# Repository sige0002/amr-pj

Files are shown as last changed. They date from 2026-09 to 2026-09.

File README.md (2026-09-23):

# AMR-01：E4 レビュー反映版

**機構設計とロボット・電装の独立AIレビューを受け、天板とスイッチ取付部を修正しました。** 天板は中央対称25穴、外周6点の極低頭固定、荷物止めは標準から撤去。スイッチはナット・工具・端末空間と配線保持を追加しました。

[設計・CAD画像](cad/amr07/reviewed-design/README.ja.md) ／ [標準BOM](cad/amr07/reviewed-design/BOM.ja.md) ／ [明細Markdown](cad/amr07/reviewed-design/BOM-details.ja.md) ／ [CSV](cad/amr07/reviewed-design/BOM.csv) ／ [配線](cad/amr07/reviewed-design/WIRING.ja.md) ／ [レビュー・対応表](cad/amr07/design-review-e3/README.ja.md)

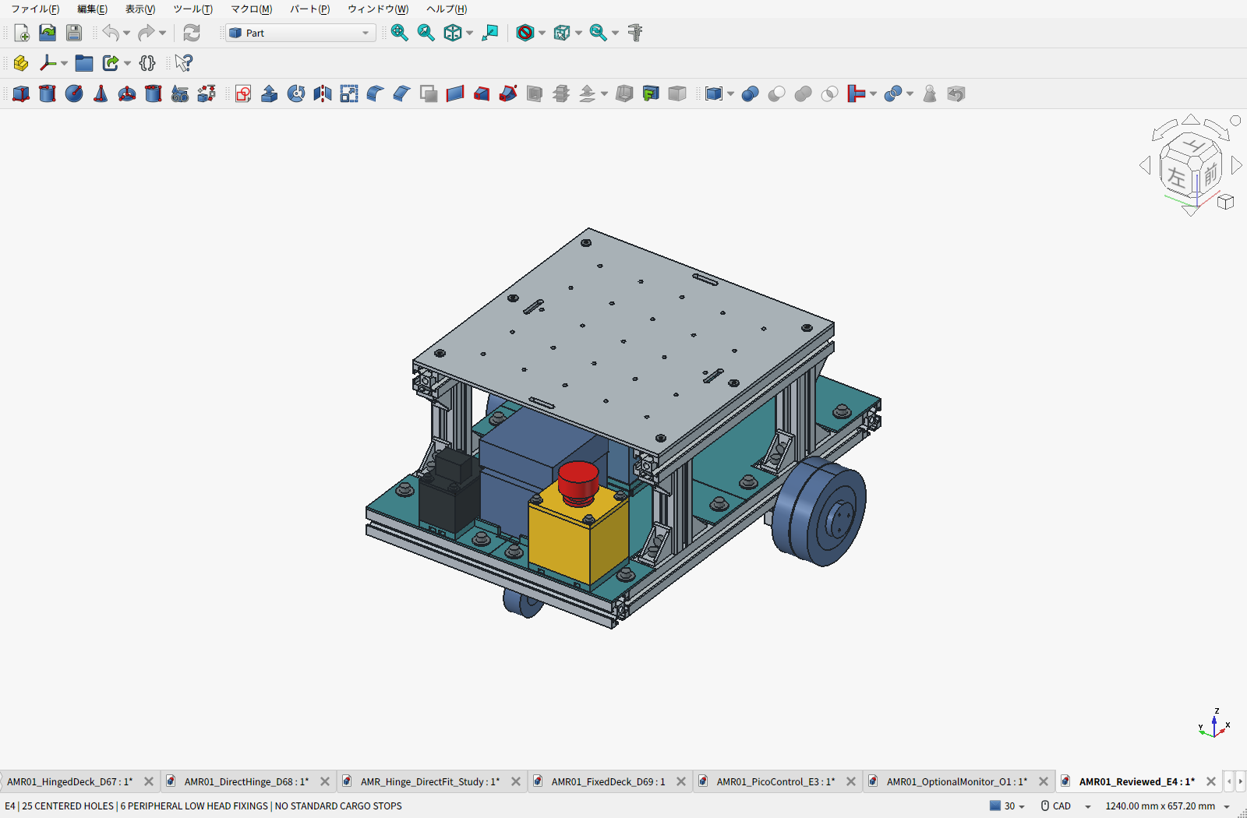
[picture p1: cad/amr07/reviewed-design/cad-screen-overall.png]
FreeCAD実画面：E4標準


標準車体推計10.363kg、通常積載10kgの設計条件。実機荷重・走行試験は未実施です。変更部8,697組で新規干渉なし。格子穴の下面工具作業とスイッチ蓋の整備は電池を外す条件です。

**計上済み小計約88,560円＋新天板・送料・PC・給電・HAT・最終配線等の未計上分。** 天板形状の変更により旧見積を外しているため、以前との差は完成車の節約額ではありません。

[モニター付きO1は別オプション](cad/amr07/monitor-option/README.ja.md)。後ろ向きの7型を左右の3030で支持する取付モックで、標準CAD・BOMには含めません。モニター機種・価格は未確定です。

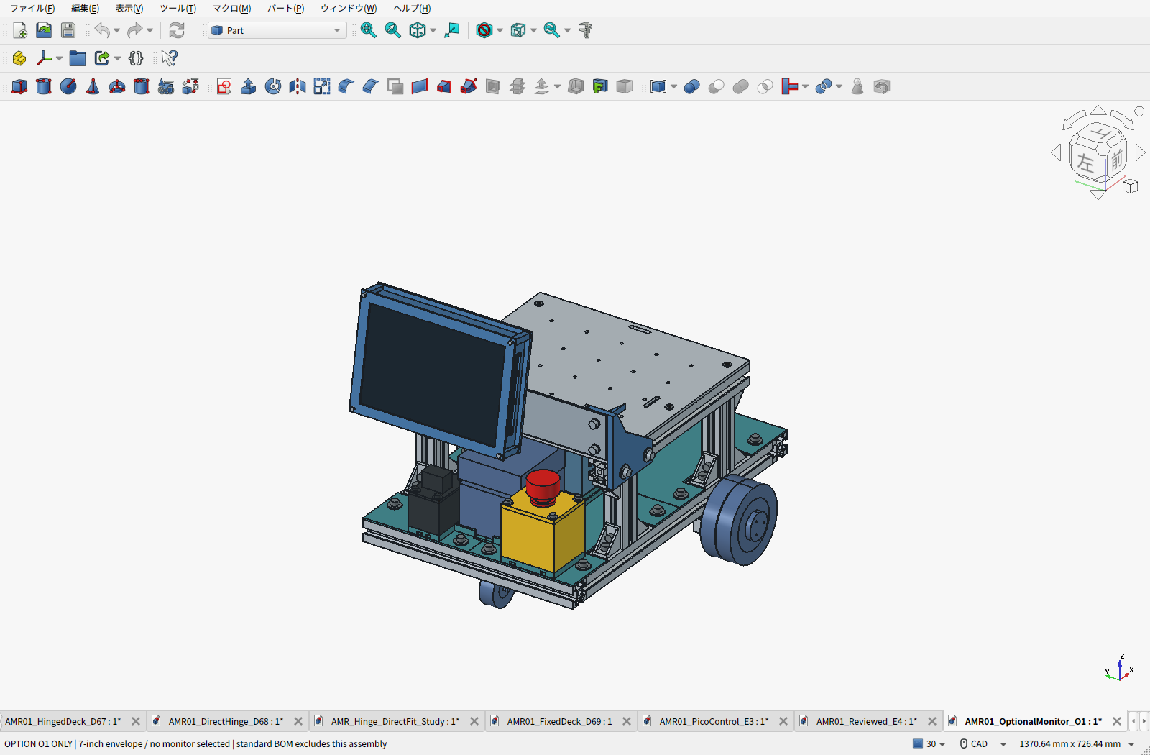
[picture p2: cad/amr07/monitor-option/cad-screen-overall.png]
FreeCAD実画面：モニターは別オプション


- [標準FreeCAD](cad/amr07/reviewed-design/AMR01_Reviewed_E4.FCStd) ／ [標準STEP](cad/amr07/reviewed-design/AMR01_Reviewed_E4.step) ／ [標準PLA試作12個ZIP](cad/amr07/reviewed-design/E4-print-prototypes.zip)
- [モニター付きFreeCAD](cad/amr07/monitor-option/AMR01_OptionalMonitor_O1.FCStd) ／ [オプション専用BOM](cad/amr07/monitor-option/BOM.ja.md)
- [天板の再計算](cad/amr07/design-review-e3/DECK_REVISION_CHECK.ja.md) ／ [干渉確認](cad/amr07/reviewed-design/validation.json)

非常停止の実負荷適合、主電源ナット/端子の実寸、PLAの長期締付保持、完成ハーネス、ファームウェア実装と試験は残っています。CADで公称配置が成立したことと、製作・通電の確定は区別しています。

## 継承した機械構成とシミュレーション

D6.5の各床4点固定、中央支持梁、四隅の連続したPLA床、計算機下の絶縁用カバーは維持しています。[床の設計](cad/amr07/two-story/README.ja.md)／[PLA床解析と限界](cad/amr07/two-story/pla-strength/README.ja.md)／[ロボコン等の参考設計](cad/amr07/two-story/REFERENCE_DESIGNS.ja.md)。

[Isaac Sim 5向けURDF・取込手順](sim/isaac_sim/README.ja.md)と[データZIP](sim/isaac_sim/amr_d65_isaac5.zip)は**D6.5時点**のモデルです。E4とモニターオプションは未反映。URDF検査とMuJoCo補助走行は実施済み、Isaac Sim本体での実行は未確認です。

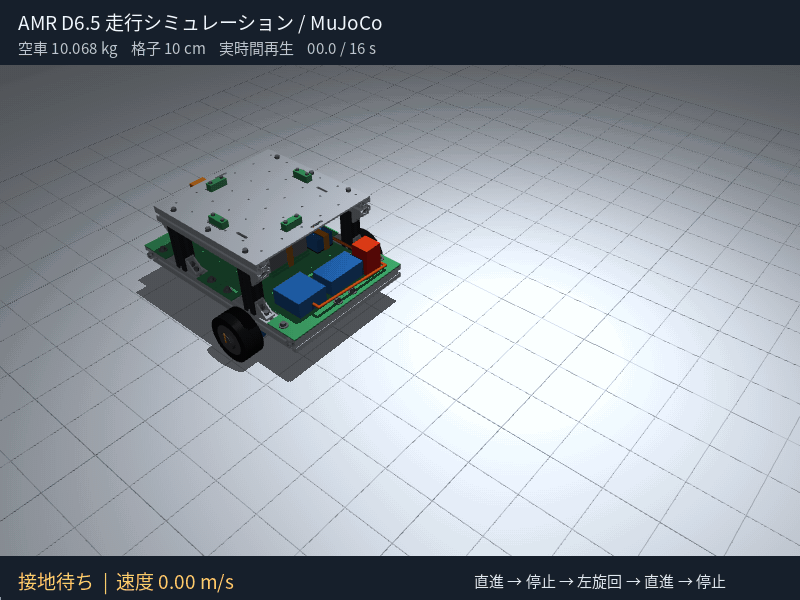
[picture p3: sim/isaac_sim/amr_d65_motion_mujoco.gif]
旧D6.5の走行シミュレーション（MuJoCo）


## 比較履歴・共通資料

- [A5：5案の実加工費・強度比較](cad/amr06/README.ja.md) / [修正元の設計レビュー](cad/amr06/DESIGN_REVIEW_2026-09-21.ja.md)
- [A4：M0601C_111と専用低背金具](cad/amr05/README.ja.md)
- [メーカーCAD・モーター仕様・タイヤ交換](cad/amr05/M0601C_INTERFACE.ja.md)
- [実加工サイト見積のスキル](skills/cnc-quote/SKILL.md)
- [A3：DDSM115](cad/amr04/README.ja.md) / [A2：FIT0185](cad/amr03/README.ja.md)
- [第二案B・却下したベルト案C](cad/amr02/README.ja.md) / [第一案](cad/amr01/README.ja.md)
- [初期基礎設計書](docs/amr-01/DESIGN.ja.md) / [FreeCAD環境](cad/README.md)

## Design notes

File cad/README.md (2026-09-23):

# FreeCAD + Codex MCP

AMRの現行案は[D6.7：開閉天板・後方操作部](amr07/hinged-deck/README.ja.md)です。BOMは[Markdown概要](amr07/hinged-deck/BOM.ja.md)／[全明細Markdown](amr07/hinged-deck/BOM-details.ja.md)／[CSV](amr07/hinged-deck/BOM.csv)で確認できます。FCStd・STEP・実CAD画面・見積用寸法図・BOM・検証結果を収録しています。[実CADによる加工サイト自動見積](amr07/MACHINING_QUOTE.ja.md)も取得済み。正式な加工審査と実機のはめあい・荷重検証は未完了。[A6-D2](amr07/README.ja.md)、[A3](amr04/README.ja.md)、[A2](amr03/README.ja.md)、[第一案A](amr01/README.ja.md)、[第二案B・ベルト案C](amr02/README.ja.md)は比較履歴です。

導入日: 2026-09-20。Ubuntu 24.04 / ARM64。

- FreeCAD 1.1.3: 公式ARM64 AppImage。公式SHA-256照合済み。
- freecad-mcp 0.1.24: uv toolで専用Python環境に導入。
- アドオン: neka-nat/freecad-mcp commit `751974609a401660a58a1772ef16f3afbeba9ba1`。
- CodexのグローバルMCP設定に `freecad` を登録済み。
- RPCは `127.0.0.1:9875` のみ。FreeCAD起動時に自動開始。

## 使う

Codexを再起動し、`/mcp` で `freecad` を確認する。
例: 「FreeCADで幅100mm、奥行60mm、厚さ4mmのプレートを作って」。

FreeCADは仮想画面上のユーザーサービスとして稼働する。
ユーザーサービス起動時にも自動開始する設定。画面キャプチャはMCPの `get_view` で取得できる。
通常のリモートデスクトップには、この仮想画面のウィンドウは表示されない。

```sh
systemctl --user status freecad-mcp
systemctl --user start freecad-mcp
systemctl --user stop freecad-mcp
journalctl --user -u freecad-mcp -n 50
```

停止・再起動前に、MCPから編集中のドキュメントを保存すること。
通常のデスクトップで開く場合は、保存して上記サービスを停止した後、
デスクトップのターミナルから `freecad /home/sadasue/amr-pj/cad/CenterHolePlate.FCStd` を実行する。
今回のリモートデスクトップ `:10.0` は、起動時にQtがクリップボードの応答を待ち続けたため、
安定稼働を確認したXvfbの仮想画面を標準のMCP実行環境とした。
デスクトップ表示の問題自体は未解消。

## 動作確認

MCPの初期化・17ツールの列挙・RPC/GUIの正常状態・モデル作成・ドキュメント一覧を確認。
別プロセスの `execute_code_headless` も検証。
60 × 40 × 5 mm、中央に直径10 mmの貫通穴がある部品を作成し、
形状の妥当性・ソリッド数1・理論体積との一致を検証した。

- `CenterHolePlate.FCStd`: 編集可能なFreeCADファイル。
- `CenterHolePlate.step`: 他のCADへ渡せるSTEPファイル。
- `CenterHolePlate.png`: プレビュー。
- `create_sample.py`: サンプル再作成コード。FreeCADのGUI内で実行する。

環境導入時の検証はFEM・CAMを含まない。後日実施したD2荷台の線形解析は[荷台解析記録](amr07/aluminum-grid-deck/README.ja.md)を参照。

## 配置

- 本体: `~/.local/opt/freecad/`
- 起動コマンド: `~/.local/bin/freecad`, `~/.local/bin/freecadcmd`
- MCP: `~/.local/bin/freecad-mcp`
- アドオン: `~/.local/share/FreeCAD/v1-1/Mod/FreeCADMCP/`
- アドオン設定: `~/.local/share/FreeCAD/v1-1/freecad_mcp_settings.json`
- サービス: `~/.config/systemd/user/freecad-mcp.service`

## 参照

- 記事: https://note.com/npaka/n/n50c8ca0ac16c
- FreeCAD公式配布: https://github.com/FreeCAD/FreeCAD/releases/tag/1.1.3
- MCP実装と導入方法: https://github.com/neka-nat/freecad-mcp
- OpenAI公式MCP設定: https://developers.openai.com/codex/mcp

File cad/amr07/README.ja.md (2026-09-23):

# AMR-01 A6-D2：格子穴アルミ荷台とPLA小物

> **電装はE1で再設計へ戻した。** 回路製作設備なしの条件に合わせ、専用基板とはんだ端子E-stopの購入案を撤回。完成回路図・配線図は未作成。[製作条件と現行BOMの訂正](electrical-buildability/README.ja.md)。

> **現行案は[D6.9：6点固定のアルミ天板・後方操作部](fixed-deck/README.ja.md)。BOMは[Markdown概要](fixed-deck/BOM.ja.md)／[全明細Markdown](fixed-deck/BOM-details.ja.md)／[CSV](fixed-deck/BOM.csv)を参照。** 通常積載目標10kg。車体10kgは厳密上限ではなく、現行の荷重計算は車体11.5kgまでの範囲。以下は旧D2の設計記録。

> **2026-09-22の方針変更：角棒の切断・穴あけを要する荷台支持案は不採用。** P0の支持棒に加え、D2の支持ブロック・ストッパーも同じ加工を要するため見直す。以下のCAD・費用・解析は変更前のD2記録。置換後の構成へ強度結果・干渉結果・見積を流用しない。[製作条件](requirements.json)

**平坦な屋内床で通常積載10kg、追加の機械ブレーキなし、構造検証は荷物15kg・静的安全率2。車体は電池・電装・荷台込み10kg以下を目標とする。** 25kgは構造検証時の総重量で、荷物25kgを載せる設計ではない。金具の機能公差・ねじ座面・ナットと溝の実寸、荷台と固定具、荷物CG範囲、停止回路構成と試験仕様を修正した。

追加機械ブレーキはユーザー方針により不採用とし、坂道走行・停電時の坂道保持を初号機の運用範囲から外した。通常の減速・停止はモーター制御、非常停止は駆動電源遮断で行う。3担当によるレビューを反映したが、**実機のSF2成立、低速連続出力、平地停止は未確認**。[指摘ごとの対応と残る確認](REVIEW_RESPONSE.ja.md)。

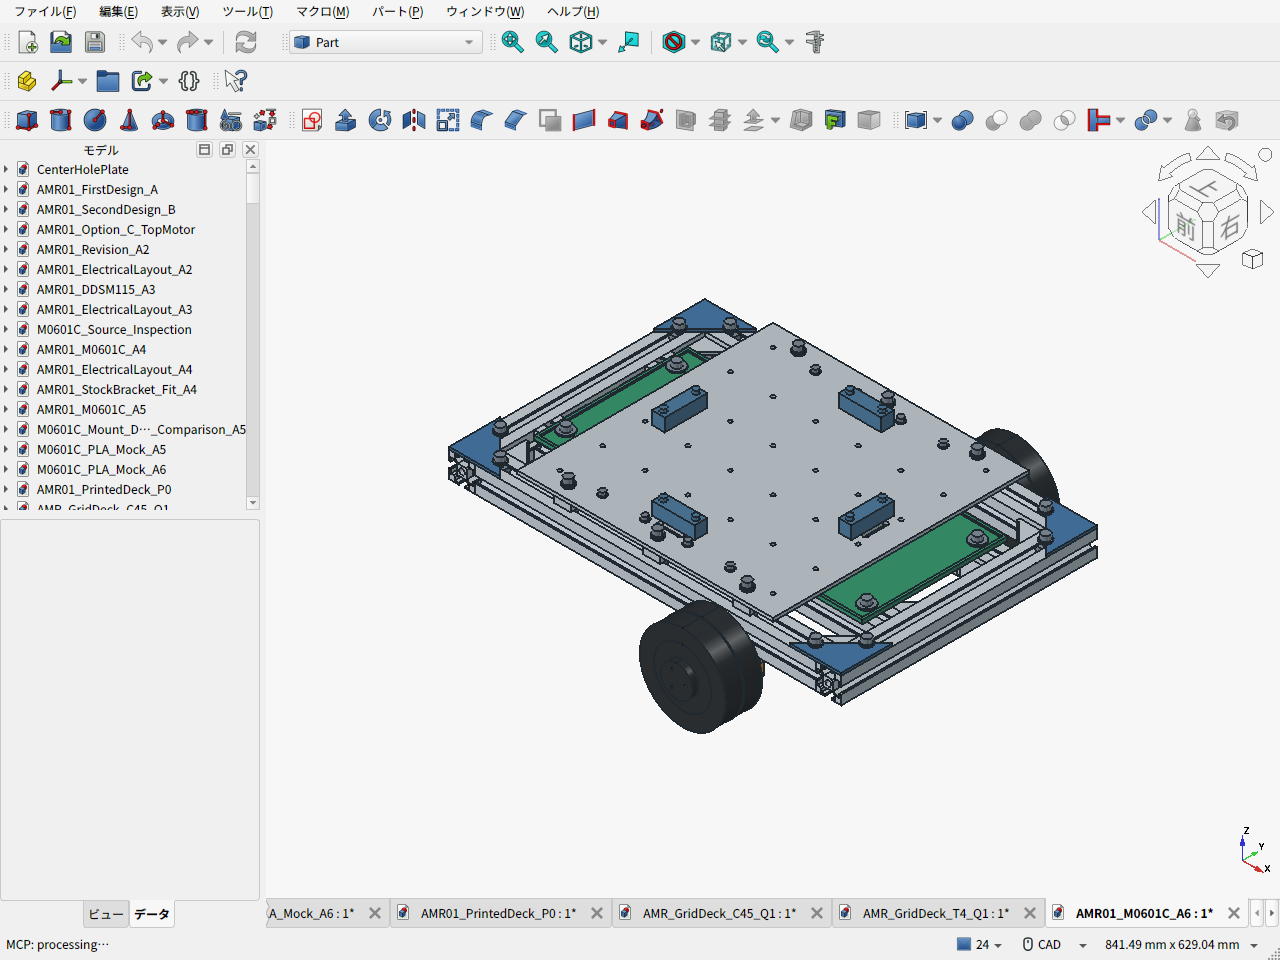
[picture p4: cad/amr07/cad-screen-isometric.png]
A6荷台付き車体・FreeCAD実画面


| 項目 | A6 |
|---|---|
| 駆動・骨格 | M0601C_111×2、100.7mmタイヤ、TYG-50、Amazon3030の400mm×4/300mm×2 |
| フレーム | 外形460×300、下面69/上面99mm。モーター支持スペーサーなし |
| 荷台 | 6061-T6 300×300×4mm、50mmピッチ36穴、上面118mm、20×15×15支持ブロック6個、金属ストッパ4個、ベルト2本 |
| 荷物 | 中央200×200mmの連続した平底。容器も荷物重量に算入。CGは前後/左右±30mm・高さ220mm以下 |
| 運用範囲 | 平坦な屋内床、通常積載10kg。追加機械ブレーキなし。8kg/5°は参考計算のみ |
| 金具 | A4相当の幅90/厚5/穴ピッチ75を維持。受け位置・φ3.2穴・小径座金と浅座ぐり・機能公差を変更 |
| ナット・溝 | HNTT6厚6.3、NFSL6入口8/最大幅16.5/深さ9の公称断面へ修正。細部は図面から再構成 |
| 重量 | **推計8.514kg**、10kgまで約1.486kg。購入部品の実測値ではない |
| CAD検査 | **298物理部品、44,253ペア、体積干渉なし**。工具、タイヤ抜出し、荷台撤去後の電池抜出し、配線予約も確認 |
| 接地 | 無変形・公称寸法で駆動輪2個とキャスターの床面z=0。実物では着座公差・タイヤたわみを調整 |
| 加工費 | A6金具2個75.02 USD＋日本宛表示送料7.23 USD＝**82.25 USD**、自動見積・手動審査前 |
| 上板実見積 | D2板1枚28.67 USD＋日本向けUPS9.98 USD＝38.65 USD、参考約6,080円。自動見積・手動審査前 |
| 板の解析 | 穴付き6支持のS6シェル、15kg＋自重・張力で最大たわみ0.207mm、全外力2倍の応力比較60.98MPa。材質条件付き、車体全体の認定とは別 |
| 費用全体 | 途中小計**50,468円＋120.90 USD＋未確定分**。キャスターはAmazon.co.jp発送・既存Prime会員の送料無料条件。完成車総額ではない |

D2で荷台支持と格子穴を修正し、PLA小物4個と締結材を加えた。新規CAD部品の質量は約1.349kg、ベルト・端保護0.280kg、ナット補正0.083kg、キャスター補正0.015kgなどを旧A4推計6.788kgへ反映した。電装2.10kg枠を1回だけ含む。全体は8.514kgで、機器実装・実測・CGの確認は残る。[質量と幾何検査](assembly_validation.json)。

- [PLA小物のSTLと組立手順](printed-accessories/README.ja.md) / [荷台・電池・キャスターの移動範囲検査](service_envelope_validation.json)
- [組立FCStd](AMR01_M0601C_A6.FCStd) / [組立STEP](AMR01_M0601C_A6.step)
- [金具STEP](M0601C_mount_A6_R1.step) / [見積図面PDF・2ページ](M0601C_mount_A6_R1.pdf) / [金具・ねじの公差と設計理由](MOUNT_INTERFACE_REVIEW.ja.md)
- [荷台の材料・穴位置・支持・固定・着脱・計算](DECK_REVIEW.ja.md)
- [拡張用格子穴・4分割PLA上板の試作CADと比較](printed-deck-concept/README.ja.md)
- [穴あき板の切り売り・Amazon板材と3Dプリントの価格比較](deck-procurement/README.ja.md)
- [D2格子穴アルミ上板のJLCCNC実見積・シェル解析](aluminum-grid-deck/README.ja.md) / [キャスターの耐荷重・Amazon／コーナン調達](CASTER_PROCUREMENT.ja.md)
- [駆動・輪荷重の計算入力](requirements.json) / [計算結果](load_calculations.json)
- [電源・停止回路の構成、候補部品、故障・熱試験](ELECTRICAL_AND_VALIDATION.ja.md)
- [BOM一覧・未選定品](BOM.ja.md) / [Excel](BOM.xlsx) / [購入品CSV](BOM.csv)
- [実加工見積と証拠](MACHINING_QUOTE.ja.md) / [費用台帳](bom.json)
- [P1S用PLA仮合わせモック](print-mock/M0601C_A6_PLA_mock_files.zip) / [印刷・仮合わせ手順](print-mock/PRINT_GUIDE.ja.md)

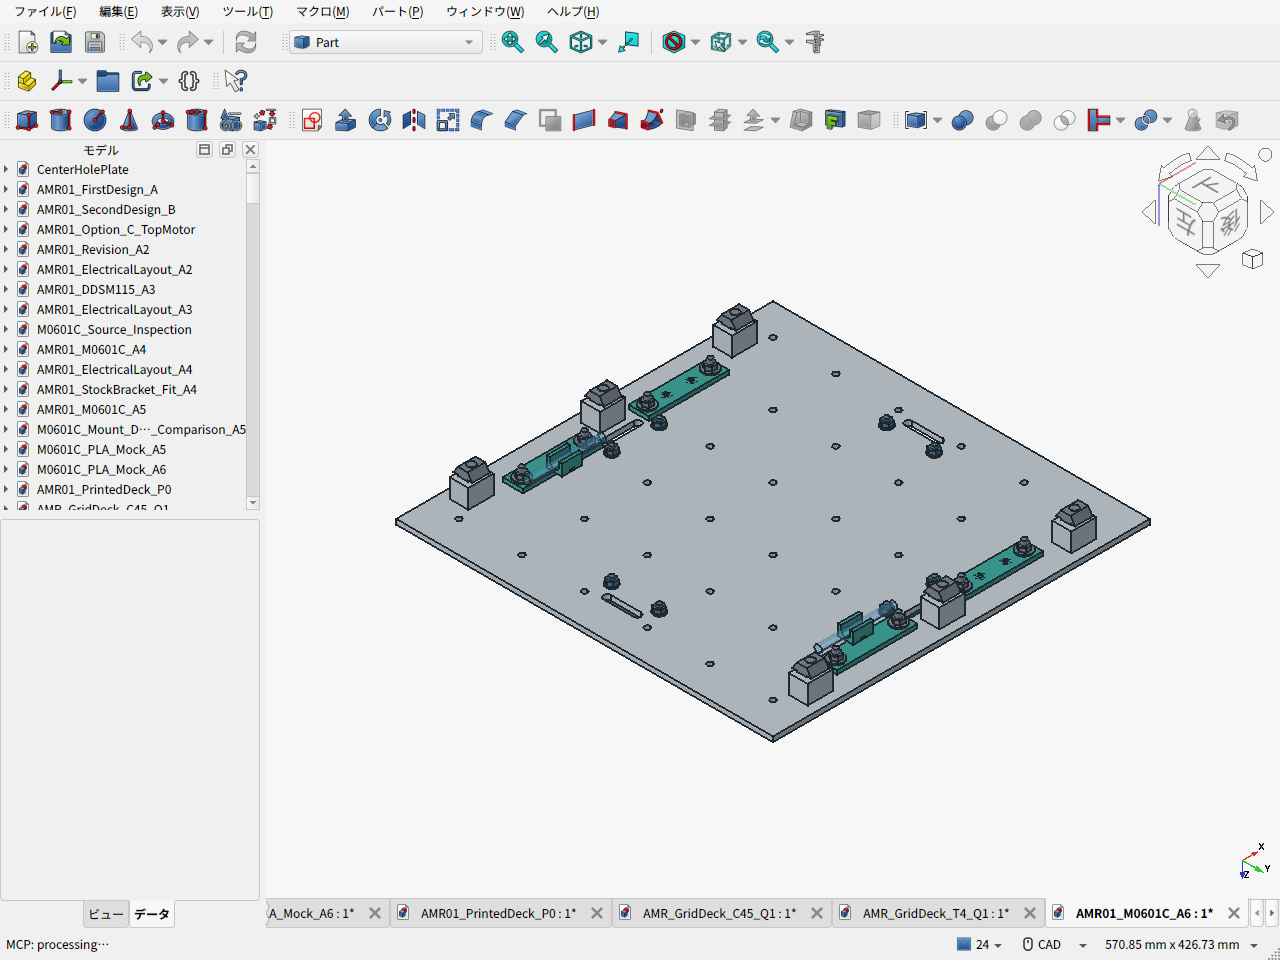
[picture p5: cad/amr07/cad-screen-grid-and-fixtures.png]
D2の支持ブロックとPLA小物・FreeCAD実画面


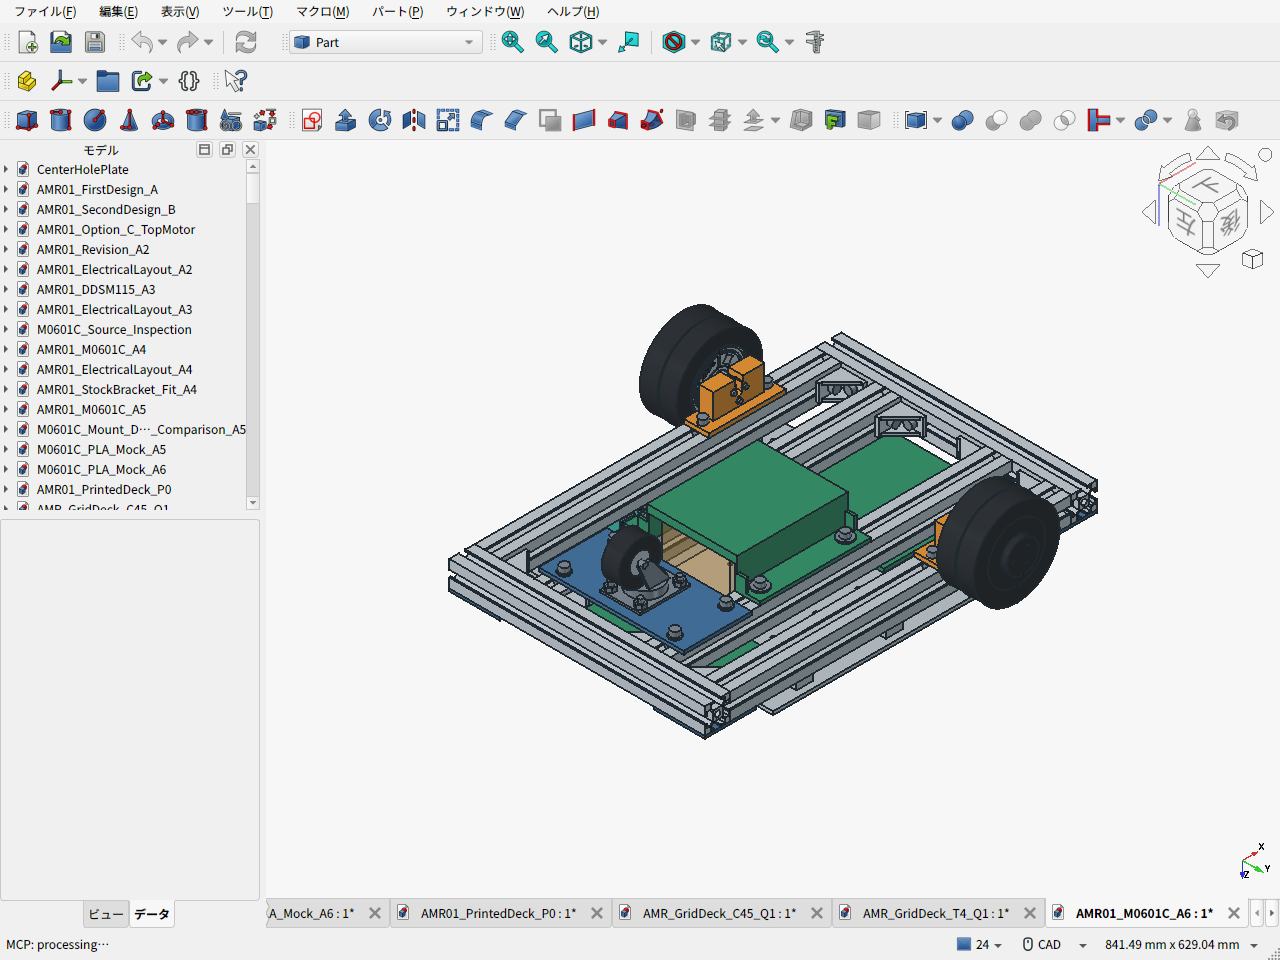
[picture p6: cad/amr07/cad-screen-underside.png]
A6下面・FreeCAD実画面


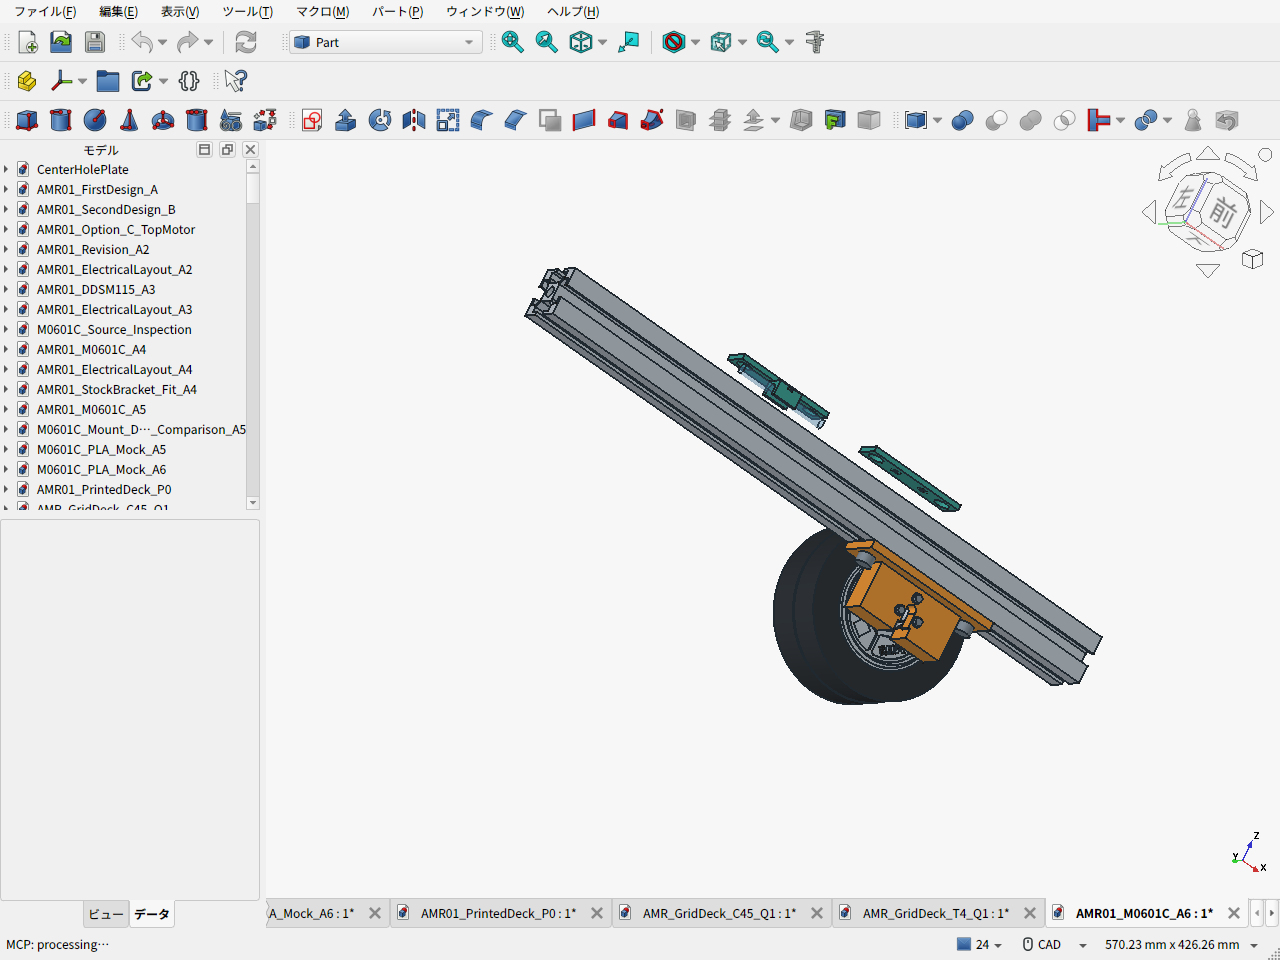
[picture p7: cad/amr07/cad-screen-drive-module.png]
車輪支持金具・小径座金・フレームへの直結


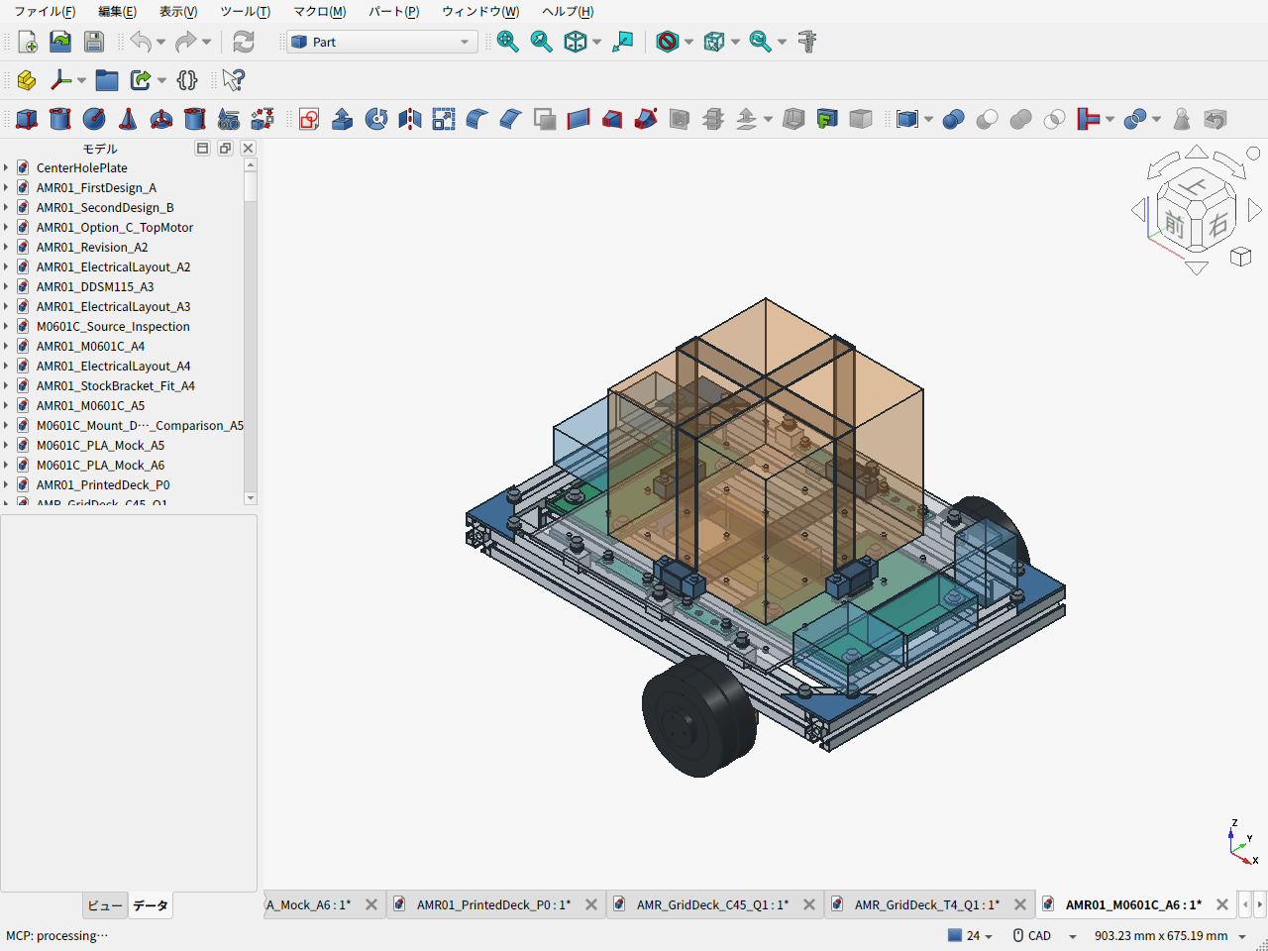
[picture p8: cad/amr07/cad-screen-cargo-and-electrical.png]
荷物と電装予約を表示したFreeCAD実画面


半透明の荷物・電装・電池は予約形状。ベルトも経路例で、完成品の詳細形状ではない。電装予約は既存ねじ頭と荷台を避けたが、汎用PLAアダプタ・局所配線ガイドを追加したが、実機器の取付・筐体・全配線の設計は残る。8kg/5°の荷重・トルクは比較用の参考値で、初号機の使用可能条件には含めない。追加機械ブレーキは従来のCAD・重量・費用小計にも含めていなかったため、今回の不採用による減額や軽量化は計上しない。

## 再生成と検査

```sh
python3 cad/amr07/calculate_design.py --check-only
python3 cad/amr07/cargo_deck.py
python3 cad/amr07/record_cost.py
python3 cad/amr07/build_bom.py
```

Excelも更新する場合は、openpyxl 3.1.5を入れたPython環境で`python3 cad/amr07/build_bom.py --xlsx`を実行する。[BOMの入力と生成物](BOM.ja.md#データと更新)を参照。

FreeCADの独立したheadlessプロセスで`aluminum-grid-deck/build_part.py`→`build_assembly.py`（モーター金具は見積済みA6-R1を維持）を実行する。`make_quote_drawing.py`は通常のPythonから実STEP投影の2ページ図面を作る。GUIでは`capture_screens.py`を実行し、保存済みファイルを開き直した上で実画面を保存する。既に開いている文書の未保存編集を上書きしない。

見積済みSTEP/PDFの変更は新改訂として再見積する。旧[A4](../amr05/README.ja.md)・[A5](../amr06/README.ja.md)の成果物は比較履歴として保持した。

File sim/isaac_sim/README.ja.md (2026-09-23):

# AMR D6.5 → URDF / Isaac Sim 5

現行の2階建てD6.5を、左右駆動輪と後方キャスターが動くURDFにしました。**Isaac Sim 5.0 / 5.1向けのデータと取込スクリプトです。Isaac Sim本体での実行は未確認です。** この作業環境には本体がなく、URDF読込・幾何検査とMuJoCoでの補助走行確認を実施しました。

[ダウンロード：URDF・メッシュ・スクリプト一式](amr_d65_isaac5.zip)

| ファイル | 用途 | 合計質量 |
|---|---|---:|
| [amr_d65.urdf](amr_d65.urdf) | 空車。電池・計算機・電装の予算を含む | 10.068kg |
| [amr_d65_payload_10kg.urdf](amr_d65_payload_10kg.urdf) | 空車＋固定した10kgの荷物 | 20.068kg |
| [import_isaac_sim.py](import_isaac_sim.py) | Isaac Sim 5で取込・物理設定・USD保存・短時間走行 | — |
| [simulation_config.json](simulation_config.json) | 車輪寸法、初期速度、摩擦・制御ゲインの仮定 | — |
| `meshes/` | CADから変換した21個の表示用STL。単位m | — |

**URDFと`meshes/`を同じフォルダー構成のまま置いてください。** ROS、xacro、ROSパッケージの設定は不要です。D6.5では中央の金属ねじ・座金を覆う連続PLAカバーを追加しました。ケース用PC座面は2mm上がって110mm、車体は約39g増です。機種未選定のため、裸基板の直接固定はこのモデルに含めていません。各床4点固定、中央支持梁と裏リブ、内側の金属フレーム金具を維持します。変換処理自体はCADを保存し直しません。

下のGIFは、このURDFをMuJoCoで物理演算して描画した走行です。空車10.068kgで、**直進→停止→左旋回→直進→停止**を16秒・等速で再生します。格子は10cm間隔。車輪の金色の線は回転を見やすくする表示上のマークで、形状・質量・接触判定は変更していません。

AMR D6.5の走行シミュレーション（MuJoCo）

[GIF単体（約3.4MB）](amr_d65_motion_mujoco.gif) ／ [描画条件・時系列・停止確認](motion_gif_manifest.json) ／ [静止画](urdf_preview_mujoco.png)

映像の生成元はMuJoCoです。Isaac Simでの実行映像や実機映像ではありません。

**Isaac Sim 5の画面から取り込む場合**

1. ZIPを展開し、Isaac Simの`File > Import`で`amr_d65.urdf`を開きます。表示されない場合は`Window > Extensions`で`isaacsim.asset.importer.urdf`を有効にします。
2. 基準単位はm、Z軸上向き。`Moveable Base`を選び、固定ベースを無効にします。`Import Inertia Tensor`を有効、`Collision From Visuals`・`Self Collision`・`Replace Cylinders with Capsules`を無効にします。固定関節の結合も無効とすると、積載版の荷物を別リンクで確認できます。
3. Joint Configurationで下表の2輪だけを速度駆動にし、キャスター2関節は`None`にします。Drive Typeは`Force`、位置剛性は0です。
4. 車体の最上位Xformを`Z=0.05235m`へ移動し、`Z=0`にGround Planeを置きます。タイヤ底面に初期2mmの隙間を設けています。車体原点は車軸中心なので、`Z=0`のままではタイヤが床に埋まります。

| 関節 | 軸 | 設定 |
|---|---|---|
| `left_wheel_joint` | +Y | Velocity / Force、最大0.96N·m |
| `right_wheel_joint` | +Y | Velocity / Force、最大0.96N·m |
| `caster_swivel_joint` | +Z | None、自由首振り |
| `caster_wheel_joint` | +Y | None、自由回転 |

左右輪の正回転で前進します。表示メッシュから衝突形状を作ると細かいねじ・溝まで計算するため、URDFに入れた箱・円柱の衝突形状を使います。インポート設定の説明は[NVIDIA公式5.0](https://docs.isaacsim.omniverse.nvidia.com/5.0.0/importer_exporter/ext_isaacsim_asset_importer_urdf.html)／[5.1](https://docs.isaacsim.omniverse.nvidia.com/5.1.0/importer_exporter/ext_isaacsim_asset_importer_urdf.html)に対応します。

**設定とUSD保存をまとめて行う場合**

Isaac Simインストール先の`python.sh`で、次を実行します。通常のPythonではIsaac Simのモジュールを読み込めません。`/path/to/amr_d65_isaac5`は展開したフォルダーへ置き換えます。リポジトリをcloneした場合は`amr-pj/sim/isaac_sim`です。

```bash
./python.sh /path/to/amr_d65_isaac5/import_isaac_sim.py --seconds 8
```

起動した専用画面で、1秒接地待ち→0.10m/sへ加速→減速停止を実行して終了します。実行前の停止状態を`output/amr_d65_scene.usda`へ保存し、関節数・総質量・実行時の位置を隣の`.validation.json`へ書きます。同名出力がある場合は`--output`で別名を指定します。

```bash
# 積載10kg、取込とUSD保存のみ
./python.sh /path/to/amr_d65_isaac5/import_isaac_sim.py \
  --payload 10 --seconds 0 --output /path/to/amr_loaded.usda

# 画面なしで、左旋回と停止を補助確認
./python.sh /path/to/amr_d65_isaac5/import_isaac_sim.py \
  --headless --speed 0 --yaw-rate 0.3 --output /path/to/amr_turn.usda
```

スクリプトは5系の`URDFCreateImportConfig`と`URDFParseAndImportFile`を使い、自由ベース、明示した慣性、キャスターの駆動解除、左右輪のトルク上限、1mmの接触オフセット、床の摩擦を設定します。参照した[5.0 API](https://docs.isaacsim.omniverse.nvidia.com/5.0.0/py/source/extensions/isaacsim.asset.importer.urdf/docs/index.html)と[5.0実装の引数](https://github.com/isaac-sim/IsaacSim/blob/v5.0.0/source/extensions/isaacsim.asset.importer.urdf/python/impl/commands.py)に合わせて作成しました。実際の環境で生成される`.validation.json`が、Isaac Sim上での確認記録になります。

**単位と運動の設定**

- `base_link`は左右車軸の中点。CAD座標では`(90, 0, 50.35)mm`、+X前方、+Y左、+Z上です。床投影の原点ではありません。
- 駆動輪径100.7mm、輪幅43mm、トレッド349mm。キャスター径50mm、トレール16mm。3輪の公称接地高さは一致します。
- 左右輪速度は`left=(v−ω×0.349/2)/0.05035`、`right=(v+ω×0.349/2)/0.05035`、単位rad/s。0.10m/s直進は左右とも約1.986rad/sです。
- 初期指令は並進±0.15m/s・旋回±0.3rad/sまで。各輪の接線速度変化を0.2m/s²で制限します。モーターの定格115rpmと車体の初期運用速度は別の制限です。
- USDのAngular Driveへ直接入れる速度は**deg/s**、IsaacのArticulation Controllerは**rad/s**です。0.10m/sは約113.79deg/s。スクリプトの速度制御ゲイン0.4N·m/(rad/s)は、USDで`Damping=0.006981317`、`Stiffness=0`、`Max Force=0.96`となります。[NVIDIAの角度・ゲイン換算](https://docs.isaacsim.omniverse.nvidia.com/5.0.0/robot_setup_tutorials/tutorial_rig_legged_robot.html)、[Articulation Controllerの単位](https://docs.isaacsim.omniverse.nvidia.com/5.0.0/robot_simulation/articulation_controller.html)

**重量・慣性の扱い**

合計は[現行D6.5の重量内訳](https://github.com/sige0002/amr-pj/blob/main/cad/amr07/two-story/payload_budget.json)と一致します。部品ごとの質量、根拠、重心、慣性テンソルを[export_manifest.json](export_manifest.json)へ保存しました。

| リンク | 空車時の質量 | 扱い |
|---|---:|---|
| 車体固定部分 `base_link` | 9.043464kg | フレーム、天板、電装、モーター固定側、キャスター取付座等 |
| 左駆動輪 | 0.450000kg | ローター仮定0.200kg＋タイヤキット予算0.250kg |
| 右駆動輪 | 0.450000kg | 同上 |
| キャスター首振り部 | 0.088716kg | キャスター全体165gを形状と材料比で配分 |
| キャスター車輪 | 0.035507kg | 同上。固定取付座の質量は車体側へ配分 |

公開モーターSTEPは内部のローター・ステーターを分離したモデルではありません。外観を取付端と外周缶に分け、1個485gのうち回転側200g・固定側285gと仮定しています。**慣性の分布には双方ともモーター全体のCAD形状を使い、固定側の質量を細い取付端だけに集中させていません。** 実測したローター慣性が得られたら更新します。タイヤキット250gも従来からの予算値です。

電池680g・アダプター123g、計算機500g等は従来の選定値／予算値。配線やベルトは質量を二重計上せず、別途分布を仮定しています。空車の荷物ベルトは天板上へ収納した質量位置、積載版は従来設計の高さ310mmへ移します。幾何から求めた空車重心はCAD座標で約`(3.11, -0.74, 122.34)mm`ですが、未測定の電装・質量分布に依存するシミュレーション値です。

積載版は200×200×160mm・10kgの一様な箱を、天板上面233mmへ固定した例です。荷物重心は313mmで、設計上の330mm以内。固定関節なので、ベルトの緩みや荷滑りは表現しません。

**実施した検証と残っている範囲**

[URDF検査結果](urdf_validation.json)：2モデルの読込、リンク木、21メッシュのパス・単位・ハッシュ、正定値かつ物理的な慣性、総質量、3輪の接地高さ、キャスター90°旋回時の軸位置、駆動方向を確認しました。

[MuJoCoの補助確認](mujoco_smoke_validation.json)：空車／積載10kgで直進・左旋回を各8秒実行し、停止、転倒なし、タイヤ以外の床接触なしを確認しました。直進距離は両方とも約0.500m。旋回角は空車約1.086rad、積載時約0.826radでした。理想運動学の1.5radより小さく、幅のあるタイヤの横滑りと仮の速度制御ゲインによる追従差が残っています。旋回方向と動作成立の確認で、旋回精度の合格判定ではありません。

摩擦係数・速度制御ゲイン・内部重量配分は初期仮定です。転がり抵抗、タイヤの変形、RS485の遅延、電源・回生・温度制限、停電をモデル化していません。速度0の駆動輪は通電中の速度制御です。機械ブレーキは追加していません。天板の穴・フレーム溝・小ねじ等は表示形状にあり、接触判定では省略しています。追加した床リブは保守的な矩形、支持梁はベルト溝を残す複数の箱で近似します。接触防止カバーは外接箱で近似し、表示用メッシュは実際のカバー形状です。このモデルの走行結果から、実機の可搬認定、登坂能力、金具の安全率は判定しません。

**再生成・再検証**

リポジトリの元CADがある環境で、FreeCADのPythonコンソールから実行します。保存済みCADを読んで変換し、元CADは保存し直しません。

```python
import runpy
runpy.run_path('/path/to/amr-pj/sim/isaac_sim/export_urdf.py', run_name='__main__')
```

通常Pythonの隔離環境で検証します。Isaac SimのPython環境へ検査用パッケージを追加する必要はありません。

```bash
python3 -m venv /tmp/amr-urdf-check
/tmp/amr-urdf-check/bin/pip install -r sim/isaac_sim/requirements-validation.txt
/tmp/amr-urdf-check/bin/python sim/isaac_sim/validate_urdf.py
MUJOCO_GL=egl /tmp/amr-urdf-check/bin/python sim/isaac_sim/smoke_mujoco.py --render
python3 sim/isaac_sim/package.py
```

描画環境がない場合は`--render`を省略できます。検証用の浮遊ベース・床・制御器はMuJoCo実行時にだけ追加し、配布URDFは変更しません。[MuJoCo公式のURDF対応](https://mujoco.readthedocs.io/en/stable/modeling.html)

GIFは同じ検査用Python環境に加え、`ffmpeg`と日本語フォントを使います。下のコマンドで走行・描画・GIF変換を再実行し、240フレームのデコード、16秒の再生時間、転倒・タイヤ以外の床接触がないこと、最後の停止も検査します。フォントの場所が異なる場合は`--font /path/to/font.ttc`を指定します。

```bash
MUJOCO_GL=egl /tmp/amr-urdf-check/bin/python sim/isaac_sim/render_motion_gif.py
python3 sim/isaac_sim/package.py
```

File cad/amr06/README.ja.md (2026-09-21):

# A5：車輪固定金具の加工費・強度比較

現在の設計は[A6：通常10kg・5°時8kg、レビュー修正版](../amr07/README.ja.md)。このA5は15kg構造検証に向けた比較履歴として保持する。
2026-09-21。**5案のSTEPと寸法図をJLCCNCで実見積した結果、今回の変更では加工費を下げられなかった。** 旧A4を価格比較の基準に残す。小型のD5は組付けCADとPLA仮合わせモックまで作成したが、製作用の採用は確定しない。A4もD5も、新しい可搬15kg・安全率2の達成は未確認である。

「可搬15kg」は暫定的に**荷物15kg＋車体上限10kg＝総25kg**と解釈する。安全率2は強度の目標とし、剛性は別に評価する。軸変位0.1mmは比較用の候補値で、受入条件は未確定。将来アームの追加重量や15kg荷台の設計は、この金具変更に含まない。

[2026-09-21の設計レビュー](DESIGN_REVIEW_2026-09-21.ja.md)で、計算と見積図の円弧公差の不一致、荷台・固定部・運用条件の未確定事項を整理した。特に隙間計算の円弧R9.7±0.05mmは見積図の指定ではなく、加工後の保証値として使用できない。

## 比較結果と採否

同形2個、Aluminum 6061-T6、表面処理なし、受け平面8.25±0.05mm、その他ISO2768-m、製造10日のサイト自動見積。送料は日本宛OCSの国単位表示7.23 USD。税・住所別費用・図面審査後の価格を含む最終決済額ではない。

| 案 | 変更内容 | 2個の加工費 USD | 表示送料込み USD | 扱い |
|---|---|---:|---:|---|
| A4 | 幅90/t5、受け小R1.65、根元追加Rなし | **74.50** | **81.73** | 最安の比較基準。新荷重要件は未認定 |
| D1 | 受け小R2、根元4辺R2 | 81.40 | 88.63 | 値下げなし |
| D2 | 受け小R2.5、根元4辺R2 | 81.92 | 89.15 | 最も高い。受け円弧も減る |
| D3 | 受け小R2、根元の長辺2本だけR2 | 80.36 | 87.59 | D1より安いがA4より高い |
| D4 | 受け小Rだけ2へ変更 | 75.02 | 82.25 | R拡大単独でも値下げなし |
| D5 | 幅75/t6、ウェブ45、M6ピッチ60、受けと長辺根元R2 | 80.08 | 87.31 | 比較CAD・仮合わせ用。加工費低減案として未採用 |

[見積条件・全証拠画面](MACHINING_QUOTE.ja.md) / [機械可読の実見積](machining_quotes.json) / [BOMへの費用差分](BOM_cost_comparison.csv) / [集計](cost_comparison.json)

円の途中小計は従来の42,282円。A4ではこれに81.73 USD、D5へ変更する場合は87.31 USDと残る未確定分が加わる。為替を仮定して合計せず、完成機総額は未確定とした。新しい荷台、電池・主計算機・電源保護・実配線、輸入諸費、PLA印刷費等も確定していない。D5を採用済みとしないため、[A4のBOM](../amr05/BOM.csv)は変更していない。

## 加工を考慮して変えた箇所

受け輪郭の6か所の小Rを揃え、深さ9mmに対して工具を太くできるかを比較した。JLCCNCの工具表ではR2/φ3の通常加工深さは12mm、R2.5/φ4は15mm。ただし実際の使用工具・加工時間は見積画面に出ないため、これは工具選定の仮説である。今回の実価格はR拡大で安くならなかった。[加工指針](https://jlccnc.com/help/article/cnc-machining-design-guideline)

水平な床と壁の根元に付けるRは、受け輪郭の内隅Rとは加工上の意味が異なる。固定Rの追加は曲面仕上げを増やす可能性がある。根元4辺、長辺2本、追加なしを実ファイルで比較した。強度上必要なRを単に価格で削る判断もしていない。[形状と実曲面の比較](candidates/ROOT_FILLET_DFM_REVIEW.ja.md)

穴はモーター側のM2.5用φ2.8×3、フレーム側のM6用φ6.6×2を維持した。役割と相手部品が異なるので同じ径へ統一しない。金具側にねじ加工・座ぐり・不要な精密公差は追加していない。この点はA4と共通で、新たな値下げ効果として計上しない。モーター受けの主円弧R9.7も適合形状なので、小R2へ揃える対象ではない。

D5では材料と外形を減らし、フランジを5→6mmにした。質量は左右合計で約44.1g減る。穴なし梁に置き換えた幅60/t5→45/t6の比較では、曲げ応力は0.926倍、たわみは0.772倍となる一方、M6間隔75→60mmでモーメントによるボルト荷重増分は1.25倍になる。完成金具の剛性が向上したという判定には使わない。

## 強度計算で分かった範囲

- 総25kgの片輪全重量ケース245.17N、全外力2倍の強度比較490.33Nを設定。通常走行の三輪反力とは区別した。
- D5の穴なし幅45/t6断面は、横力ゼロの使用荷重で35.87MPa、全外力2倍で71.73MPa。これには受け接触、M2.5母材、締付予圧、根元・孔の局所応力、3030溝の変形は含まれず、部品の安全率2は未判定。
- 25kgで旧条件の5°登坂・加速度0.2m/s²・駆動余裕1.5を維持すると1.272N·m/輪が必要で、公表定格0.96N·mを超える。同条件の平地は0.467N·m/輪だが、低速の連続温度は未確認。
- メーカー現行の許容ラジアル120Nは、偏積み例の151Nより小さい。購入ロットへの適用と荷重点・寿命条件の確認が必要で、金具だけを強くして解決する条件ではない。

[要求・全計算・接合部の未確認事項](STRENGTH_REVIEW.ja.md) / [入力](requirements.json) / [計算結果](load_calculations.json) / [メーカー現行仕様](https://shop.directdrive.com/pages/m0601c-111-specs)

## 比較CADと公称組付け検査

[車体FCStd](AMR01_M0601C_A5.FCStd) / [車体STEP](AMR01_M0601C_A5.step) / [金具3案の比較FCStd](M0601C_Mount_DFM_Comparison_A5.FCStd) / [D5単品STEP](candidates/M0601C_mount_D5_Compact_R2.step) / [D5寸法図](candidates/M0601C_mount_D5_Compact_R2.pdf)

組立はD5の金具2個と、それに伴うM6・溝ナットの位置だけを変更した。3030フレーム、モーター、タイヤ、キャスター、低床電池配置を維持する。

| 検査 | 結果 |
|---|---|
| 部品干渉 | 161部品、12,880組。包絡で絞った332組を体積検査し、干渉なし |
| 地面 | 左右タイヤ・キャスターとも公称接地点z=0 |
| 高さ・外形 | 軸高50.35、フレーム下面69、金具最低35、骨格460×406.6×109.6mm |
| 整備空間 | 工具軸とタイヤ引抜き6位置、計22条件で干渉なし |
| 配線・電池 | A4の予約空間と変更金具の干渉なし |
| M2.5頭と根元R | 公称最短距離0.8mm |
| M6×12 | 先端z75、簡略ナットz71〜75。面取り・不完全ねじを含む有効食込みは未確認 |
| STEP再読込 | valid、165 solid、体積差0.1023mm³ |

[全検査記録](assembly_validation.json)。これは公称配置の検査であり、変形・公差・衝撃・寿命の検証ではない。タイヤの軸方向位置はA4同様に暫定で、実物との照合が残る。

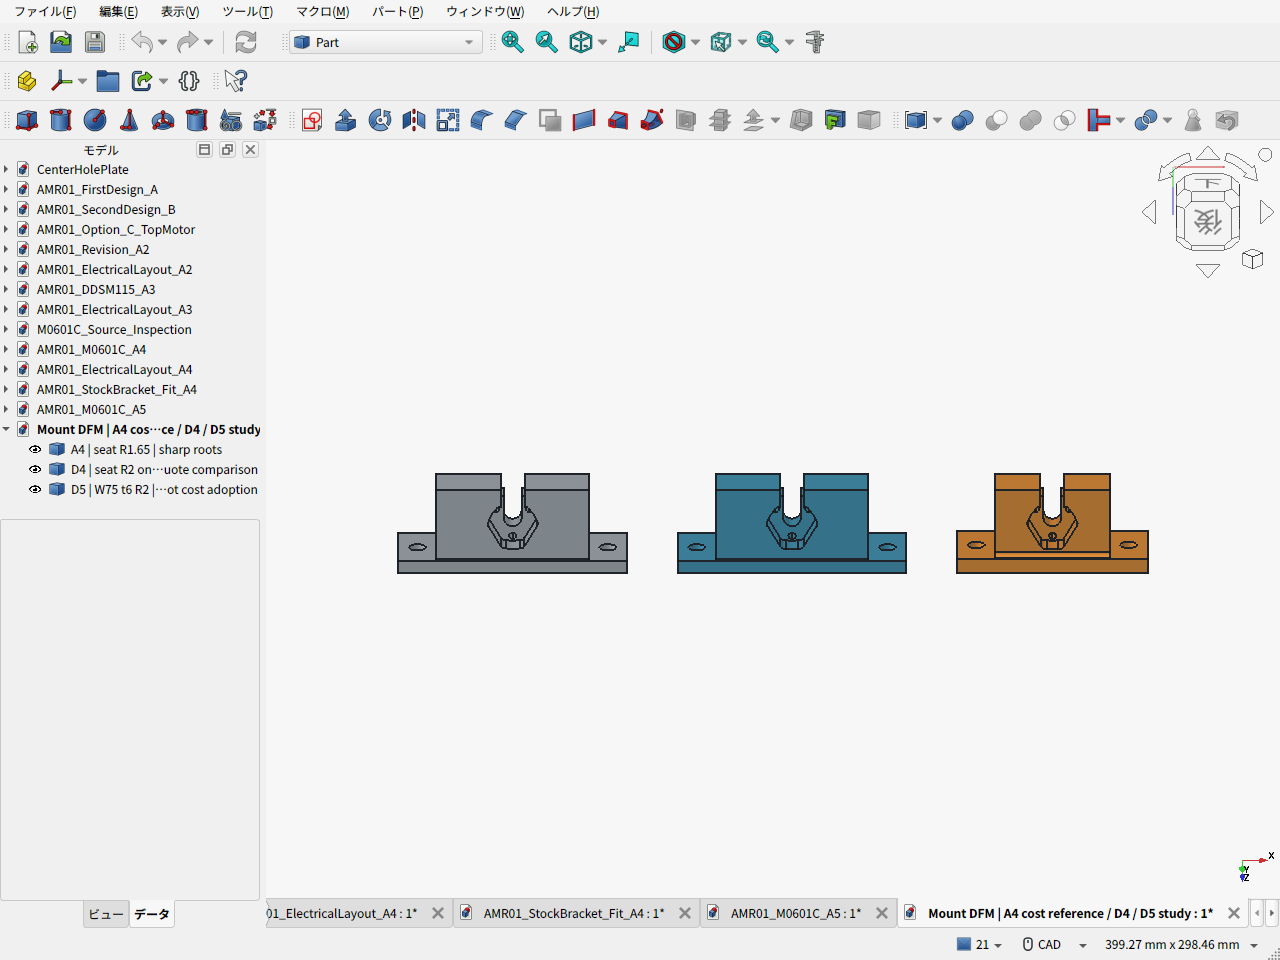
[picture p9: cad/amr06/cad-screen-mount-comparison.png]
A4灰・D4青・D5橙のFreeCAD実画面


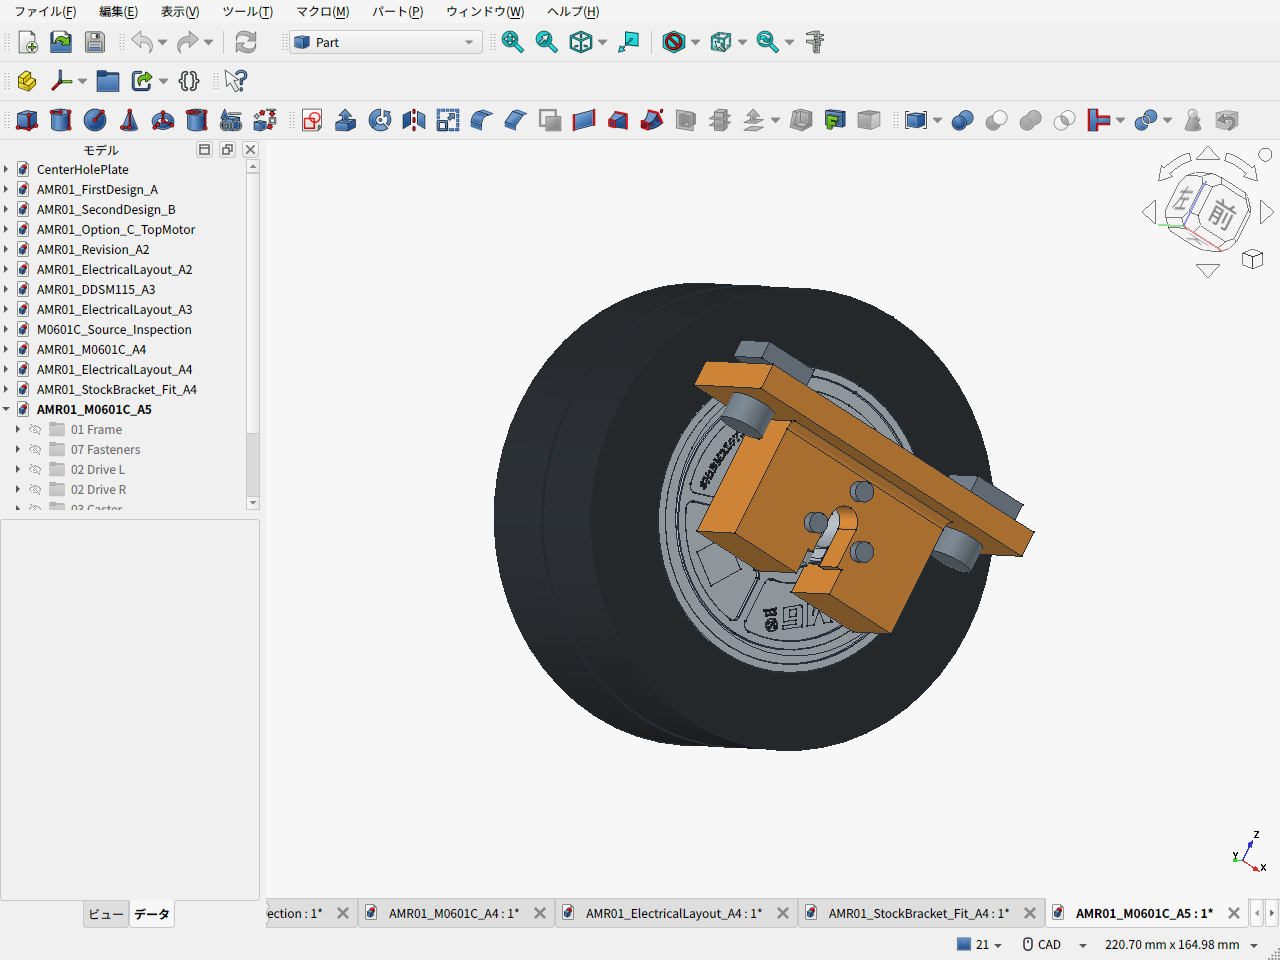
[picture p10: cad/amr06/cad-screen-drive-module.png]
D5とM0601Cの組付け・FreeCAD実画面


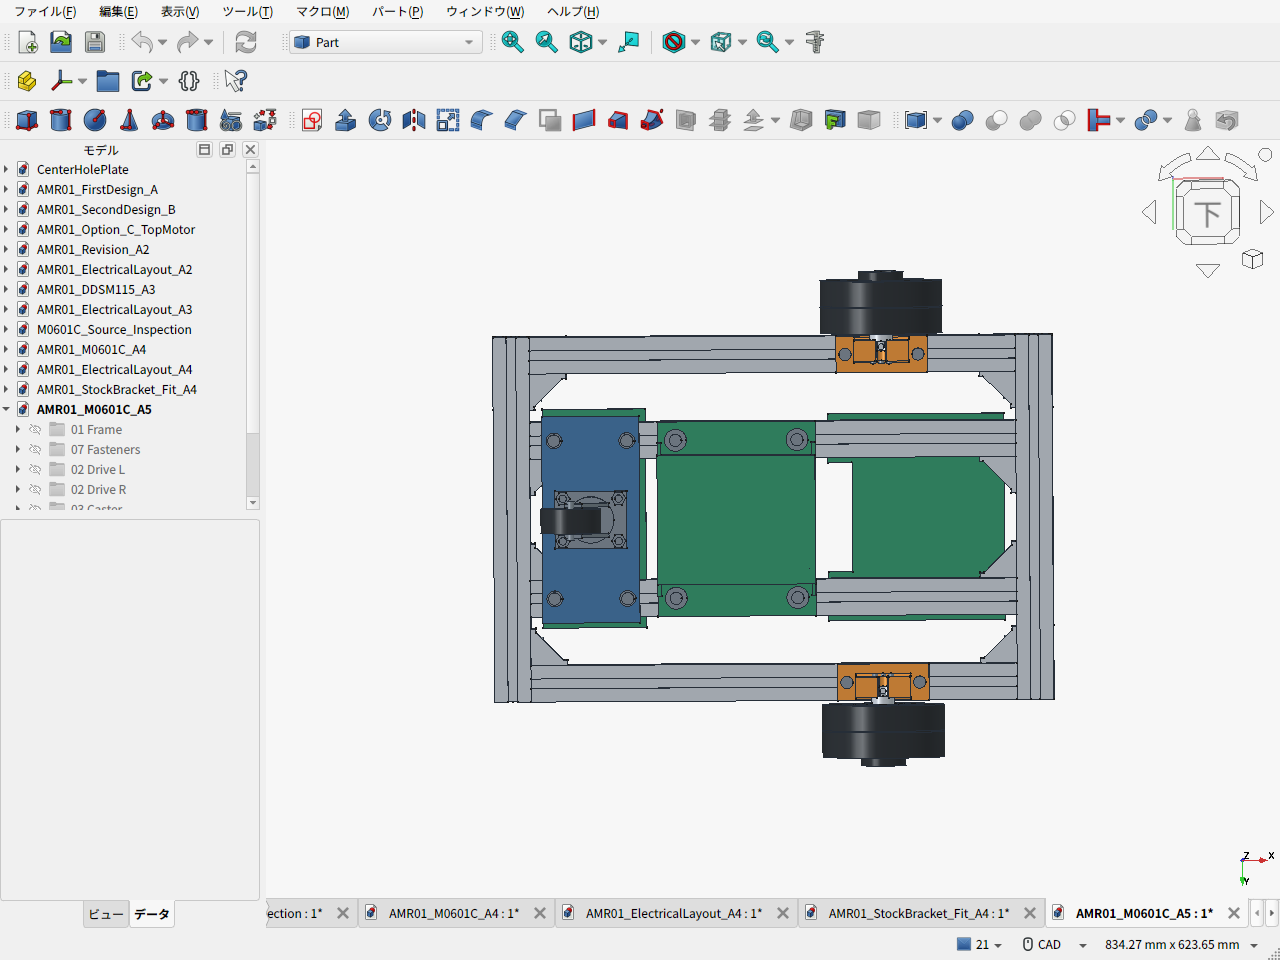
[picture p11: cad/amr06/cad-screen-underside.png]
車体下面のFreeCAD実画面


## P1SでのPLA仮合わせ

[印刷用ZIP](print-mock/M0601C_A5_PLA_mock_files.zip) / [印刷・仮合わせ手順](print-mock/PRINT_GUIDE.ja.md) / [STL検証](print-mock/validation_results.json)

D5の等倍本体75×30×34mmと、受け確認片24×29×17mmを作成した。P1Sの公称造形範囲256mm角内に収まる。まず小さい確認片で受け、穴、配線逃げを確かめ、本体で3030・工具・モーターの配置を仮合わせする。PLAは強度試験や15kg積載走行用の主支持金具にはしない。スライス・印刷・現物合わせは未実施で、印刷時間と費用も未計上。

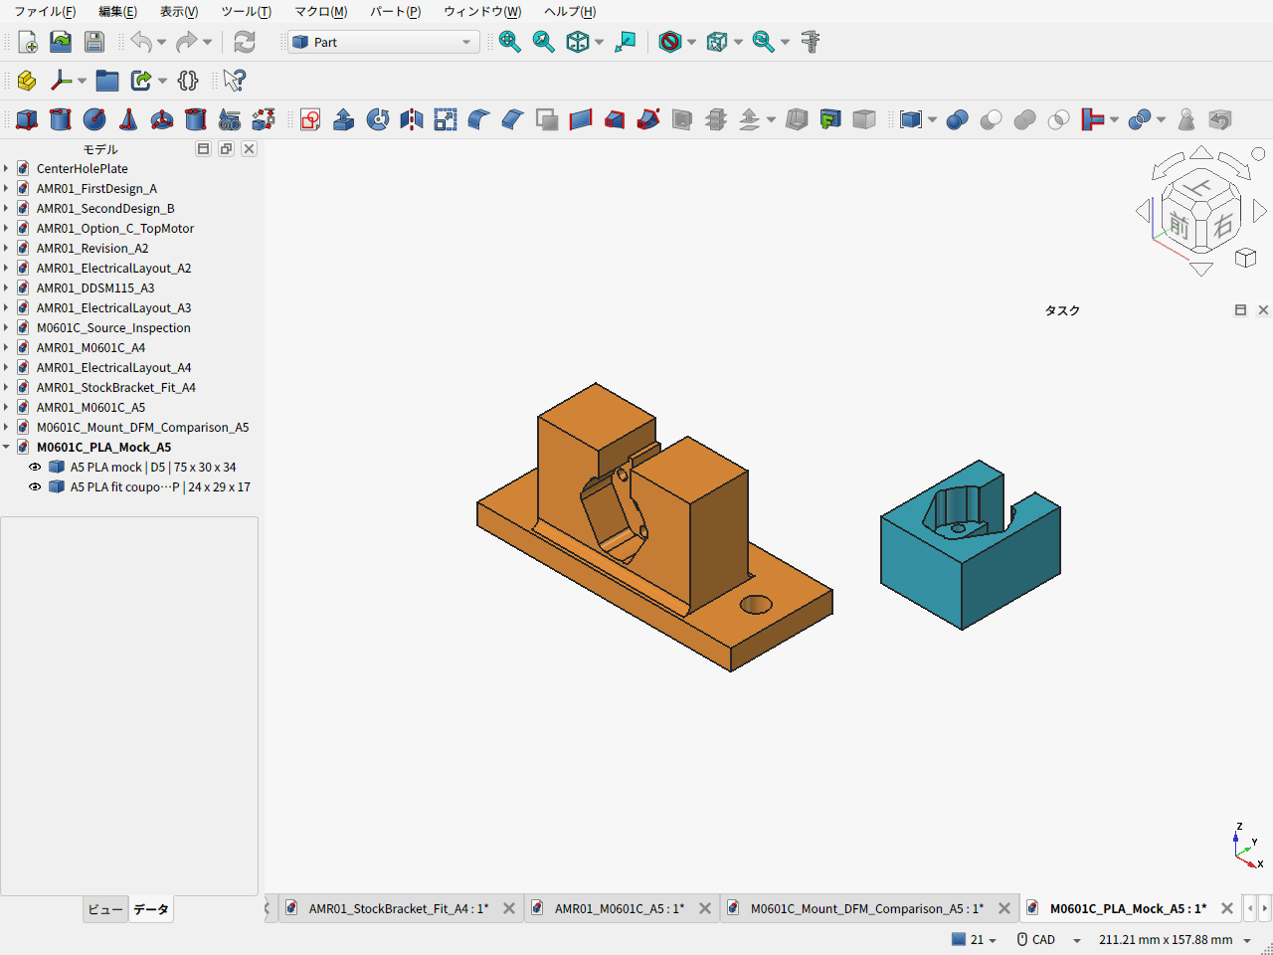
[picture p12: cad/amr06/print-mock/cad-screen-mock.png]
PLA仮合わせ本体と受け確認片のFreeCAD実画面


## 再計算・再生成

```sh
python3 cad/amr06/calculate_mount_loads.py --check-only
python3 cad/amr06/record_quote_results.py
python3 cad/amr06/calculate_cost_comparison.py
python3 cad/amr06/build_mount_candidates.py --candidates D1 D2 D3 D4 D5
python3 cad/amr06/make_quote_drawings.py --candidates D1 D2 D3 D4 D5
```

見積記録スクリプトは保存済みサイト証拠を照合し、価格を再取得するものではない。見積に使ったSTEP/PDFはハッシュで固定し、形状変更時は新候補として再見積する。

`build_assembly.py` と `build_print_mock.py` はFreeCAD Pythonで実行する。例えばリポジトリのルートから次で車体を再生成できる。

```sh
freecadcmd -c 'p="cad/amr06/build_assembly.py"; exec(compile(open(p).read(), p, "exec"), {"__name__":"__main__", "__file__":p})'
```

GUIで開いた生成対象は保存要否を確認して閉じてから再生成し、ディスク上の最新FCStdを開いて `capture_screens.py` で実画面を撮影する。モックは `build_print_mock.py` の `finalize_gui_preview()` で表示を保存し、ZIP内のCAD・画像・ハッシュを同期する。

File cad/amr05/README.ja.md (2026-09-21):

# 第一案改A4 — M0601C_111と専用金属ブラケット

2026-09-21。**M0601C_111を採用し、公開ブラケットのモーター受けを参照した低背の一体金属金具へ設計を変更した。** 通常の既製金具を使う案もCADに配置したが、現フレームでは干渉する。専用品の実STEP・PDFをJLCCNCへ投入し、[2個と送料81.73 USDのサイト自動見積](MACHINING_QUOTE.ja.md)を取得した。加工先の正式審査・現物のはめあい・実荷重の検証は未完了。

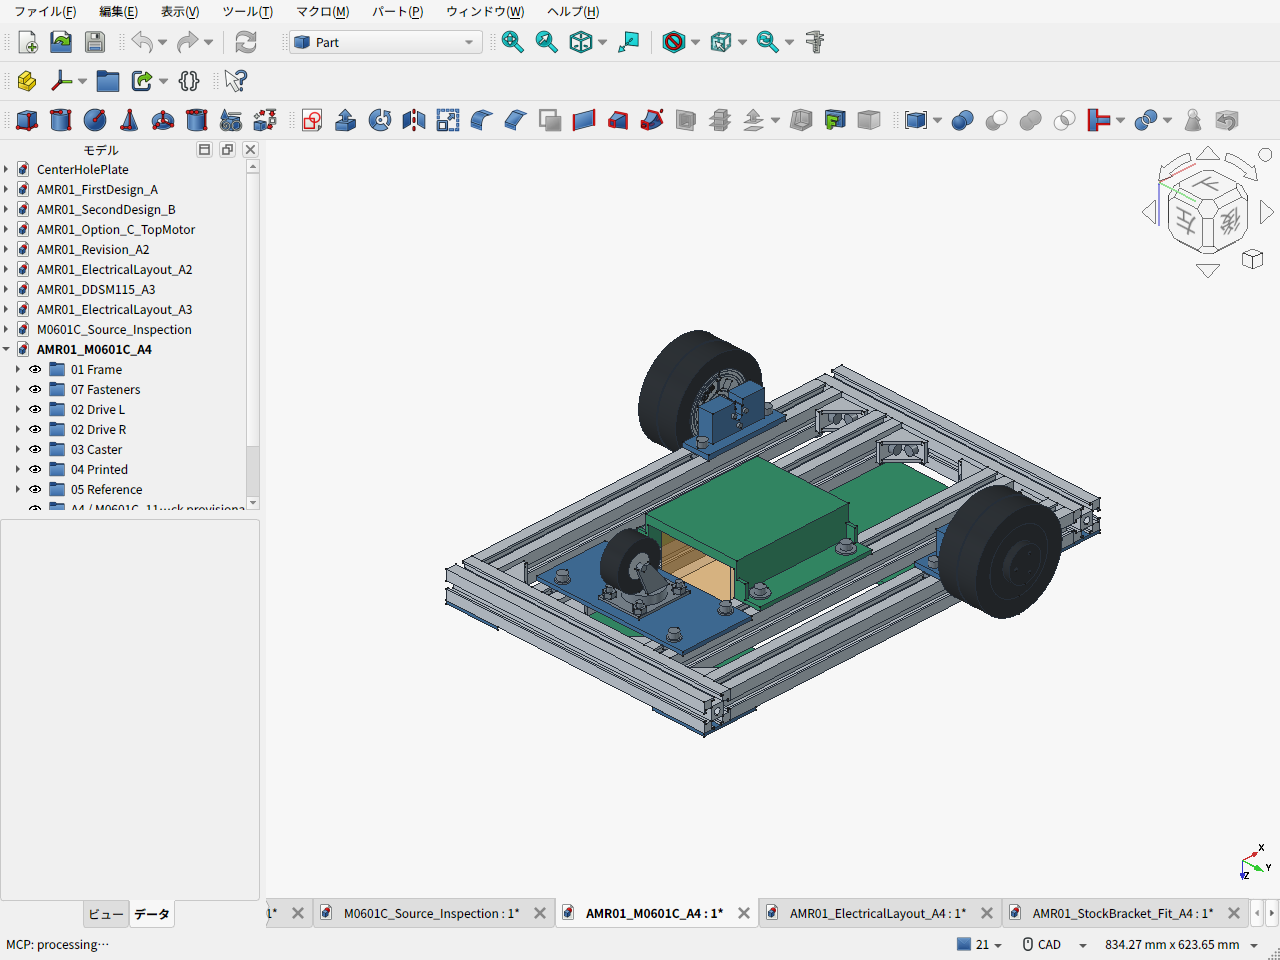
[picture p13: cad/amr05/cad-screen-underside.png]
A4のFreeCAD実画面


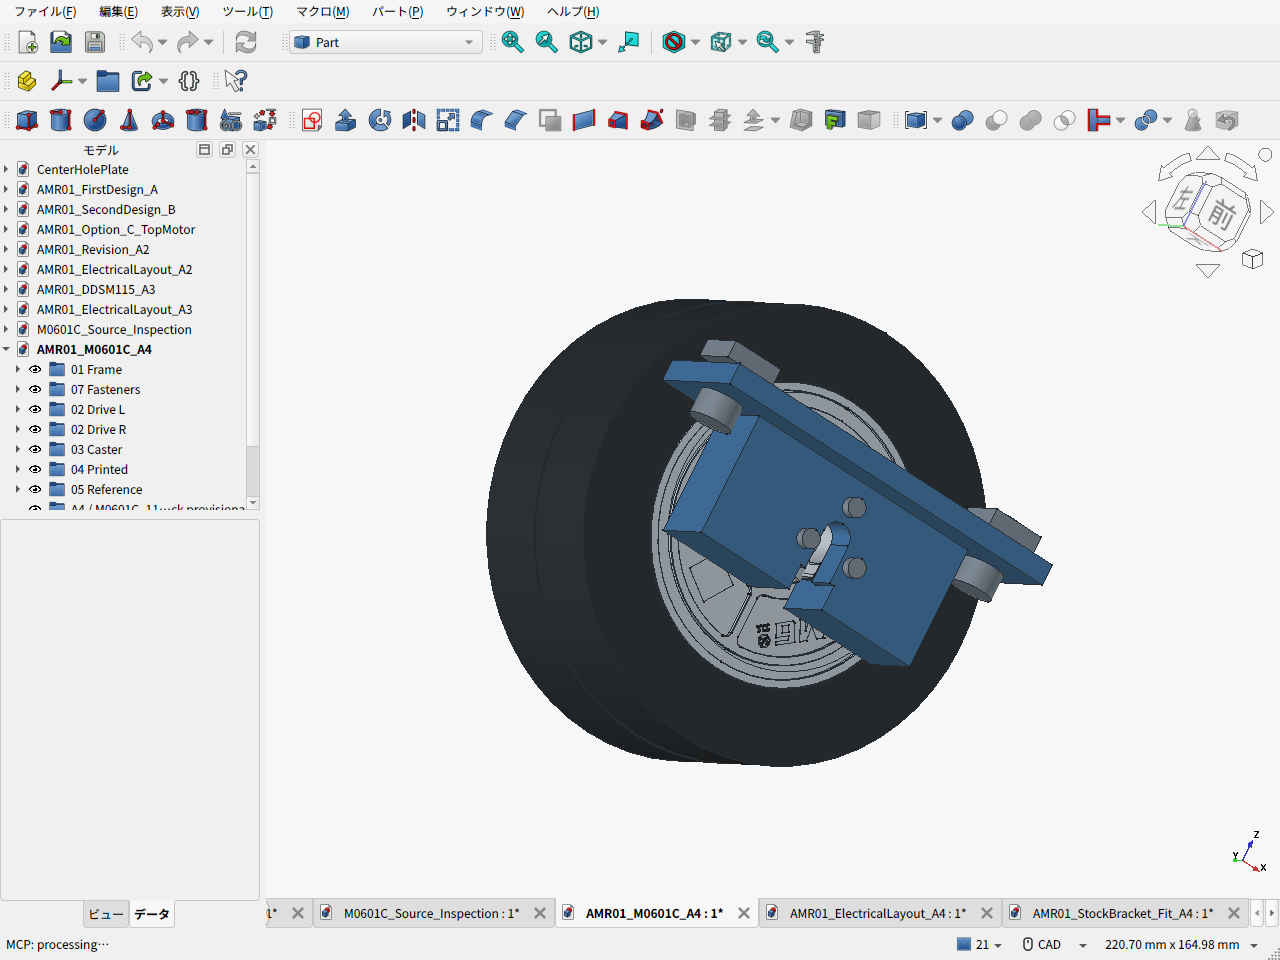
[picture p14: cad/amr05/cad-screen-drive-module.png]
モーター内側と一体金属金具の実画面


## 配置と設計理由

| 項目 | A4 |
|---|---|
| 骨格 | Amazonの3030・400mm×4本、300mm×2本。460×300mm、元のレール位置を維持 |
| フレーム接合 | MISUMI HBLFSN6-SET×8。個人購入経路と納入額は引き続き未確定 |
| 駆動 | M0601C_111×2、適合DDT-M0601C-TIRE×2、後方420G-R50キャスター |
| 金具 | A6061-T6候補、一体90×30×34mm。同一部品2個、左右は180°回転して使用 |
| 受け | 公開CADの16曲線を参照。輪郭を0.15mm拡張、支持深さ3→9mm、背肉8mm |
| モーター締結 | M2.5×12を3本/輪。公称ねじ込み4mm、資料の穴深さ5mmに対し1mm余裕 |
| 3030締結 | 厚さ5mmのフランジを下面へ直接固定。M6×12を2本/輪、溝ナット。スペーサーなし |
| 配線 | 背面の幅7mm溝から組付け、前面/下側を9.5mmに拡幅。小ねじ頭の座面を残す |
| 高さ | フレーム下面69mm、電池搭載面35mm、金具下端35mm、固定骨格最低32mm |
| 車体質量 | 電装2.10kgの枠を含む推計6.79kg。目標10kg以下、未実測 |
| 走行計算 | 最大構成14kg、5°、加速0.2m/s²、仮の転がり係数0.03、余裕1.5で0.713N·m/輪。公表定格0.96N·m/18V |
| 外形 | 仮のタイヤ組付け位置で460×406.6×109.6mm、輪距349mm |

金具を3030の直下へ置き、車輪からの力を受けポケット・金具・フランジ・M6/溝ナットへ短く伝える。A3の二つのアングルと別体キー板の組合せを廃止した。PLAは電池クレードルと電装トレイに使用し、主輪の支持には使わない。

駆動タイヤとキャスターの**接地面はどちらもz=0**。駆動輪の軸高さ50.35mm、キャスターの軸高さ25mmで、軸同士を同じ高さにする構成ではない。キャスター取付高さ65mm＋取付板4mm＝フレーム下面69mmとして揃えている。荷重によるたわみ・タイヤ摩耗・製作公差は、この公称CADの一致に含まない。

受け深さを増やすと短い固定端の曲げ支持に使える距離を増やせる。ただし、ポケットは隙間ばめで、小ねじが無荷重になるわけではない。部材・小ねじ・レール接合の力の比較は[独立レビュー](MOUNT_REVIEW.ja.md)に記載。FEM・衝撃・疲労・締付条件の認定はしていない。

## 既製ブラケットの配置結果

元SLDPRTの保存表示メッシュを抽出して配置した。**全体を厳密なSTEPへ変換したものではない。** 受け部だけは元の解析曲線を再構築し、座面メッシュと数値照合した。[抽出根拠](BRACKET_SOURCE_REVIEW.ja.md)

| 姿勢 | 最下端 | 元の外レール |
|---|---:|---|
| 通常 | −39.65mm | 干渉 |
| 90°回転 | 15.35mm | 干渉、目標地上高25mm未達 |
| 上下反転 | 25.35mm | 干渉。地上高の公称余裕も0.35mm |

固定端面をy138に保ちt5取付板を使うなら、外レールを24mm内側へ移す必要がある。既存の内レールとの間隔と純正接合金具の配置も変わるため、今回は専用品を優先する。既製品自体が不適切な製品という判断ではない。[配置CAD](AMR01_StockBracket_Fit_A4.FCStd) / [検査値](stock_bracket_fit_results.json) / [実画面](cad-screen-stock-bracket-fit.png)

## 費用と見積資料

約7,000円/個のTaobao本体にタイヤが含まれるかは未確認。下表は参考価格と材料等の仮枠を含む**途中小計**で、完成機価格ではない。

| 購入条件 | 途中小計 |
|---|---:|
| 本体のみと仮定、適合タイヤキット2個を別購入 | **42,282円** |
| タイヤ・必要なカバー/ねじの付属を注文先で確認できた場合 | **33,042円** |

専用金具2個の材料込み加工は74.50 USD、日本宛OCS送料表示は7.23 USD、計81.73 USDの自動見積を別通貨で計上した（製造10日）。正式審査後の加工費、税・住所別送料・円決済額、Taobao納入諸費は未確定。共通のキャスター板/ガセットを自加工する条件であり、これらも外注する場合は別の見積項目が加わる。電池・主計算機・電源保護・車内配線等は別予算。旧取付材2,800円と旧未見積加工枠6,000円は重複計上していない。[実見積の条件と証拠画面](MACHINING_QUOTE.ja.md)

既製金具は2個12,100円＋車体側取付板等で比較する。専用品が安いという仮定で採用しておらず、見積結果で調達方法を確定する。[BOM](BOM.csv) / [計算結果](cost_summary.json) / [価格の根拠と比較](COST_REVIEW.ja.md)

加工業者へ渡す資料：

- [金具の見積用STEP](M0601C_custom_mount_quote.step)
- [寸法図PDF](M0601C_custom_mount_quote.pdf) / [SVG](M0601C_custom_mount_quote.svg)
- [数量・材料・重要寸法・見積範囲](MANUFACTURING_RFQ.ja.md)

これらは見積用。購入ロットの取付端寸法、輪郭全体のはめあい、加工R、公差、締付条件を確定してから製作へ進む。

## CADと検証

- [車体FCStd](AMR01_M0601C_A4.FCStd) / [車体STEP](AMR01_M0601C_A4.step)
- [配線・機器予約空間FCStd](AMR01_ElectricalLayout_A4.FCStd) / [配線・整備説明](ELECTRICAL_PACKAGING.ja.md)
- [本体CADと取付寸法の扱い](M0601C_INTERFACE.ja.md)
- [161部品・12,880ペアの形状検査](validation_results.json)：公称体積干渉なし、電池空間干渉なし、キャスター72姿勢干渉なし
- [工具軸・タイヤ移動の空間検査](mount_service_validation.json)
- [電装配置検査](electrical_layout_validation.json)：11経路に未許容の車体干渉・配線交差なし
- [駆動/静的支持/摩耗感度](calculation_results.json)
- [PLAクレードル](BatteryCradlePLA.stl) / [後部トレイ](ElectronicsTrayPLA.stl) / [前部トレイ](FrontElectronicsTrayPLA.stl)：各1個、P1Sの256mm角へ収まる

モーター本体は販売元が案内するSTEPを使用した。元データの柔軟なケーブル姿勢は剛体の干渉対象から外し、別文書で経路を作り直した。ねじ山の谷径は、ねじ外形の検査用に局所的に開いている。タイヤとカバーは公開外形に基づく簡略形状で、**キットの軸方向組付け位置が未確認**。全幅406.6mmと輪距349mmはその仮定を含む。

配線予約の最下端は約28.35mmで、固定骨格32mmとは別。タイヤの荷重変形・摩耗・取付公差を含めた地上高25mmの実機保証ではない。ケーブル保持、電池保持、車輪荷重・衝撃、低速発熱も実機確認が必要。

## 再生成

```sh
python3 cad/amr05/fetch_vendor_cad.py
python3 cad/amr05/calculate_cost.py --require-cad --self-test
python3 cad/amr05/calculate_design.py
```

FreeCADのPython環境で、`__file__`と`__name__='__main__'`を与えて順に実行する：`build_chassis.py` → `validate_chassis.py` → `build_electrical_layout.py` → `validate_mount_service.py` → `build_stock_bracket_study.py` → `capture_screens.py` → `capture_electrical_layout.py`。寸法図の再生成は`make_mount_drawing.py`を参照。

[旧A3](../amr04/README.ja.md)は比較履歴として保存している。

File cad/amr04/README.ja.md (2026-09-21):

# 第一案改 A3 — DDSM115一体ホイール

> 比較履歴です。現行案は[M0601C_111のA4](../amr05/README.ja.md)。

2026-09-20 / v0.7.0。走行余裕を優先して、第一案改A2のFIT0185・継手・長い車軸・外付け軸受をDDSM115へ置き換えたCAD案。Amazonで扱う3030の300/400mm定尺、低い電池位置、スペーサーなしの方針を維持する。ベルトは使わない。

**タイヤの摩耗寿命と交換タイヤの確実な調達先は未確認。** ゴムタイヤを脱着できることはメーカー資料で確認したが、補修品が安く買えるとまでは判断できない。[タイヤ摩耗・保守レビュー](TIRE_WEAR.ja.md)を採用判断に追加した。

## CADと実画面

- [FreeCAD本体](AMR01_DDSM115_A3.FCStd) / [機械部品STEP](AMR01_DDSM115_A3.step)
- [電装・配線・整備空間のCAD](AMR01_ElectricalLayout_A3.FCStd) / [配置の説明](ELECTRICAL_PACKAGING.ja.md)
- [部品表](BOM.csv) / [購入単位と価格区分](bom.json) / [費用集計](cost_summary.json)
- [設計条件](design_parameters.json) / [形状・重量検査](validation_results.json) / [駆動・静的反力・摩耗感度](calculation_results.json)
- [モーターの費用・性能比較](MOTOR_COMPARISON.ja.md) / [取付インターフェース根拠](DDSM115_INTERFACE.ja.md) / [金属マウントの独立レビュー](MOUNT_REVIEW.ja.md)

以下はFreeCADの実ウィンドウを保存した画像。モーターは公式外形・取付寸法に基づく簡略形状で、内部の軸受やタイヤの詳細嵌合を再現していない。茶色の半透明箱は未選定電池の予約空間。

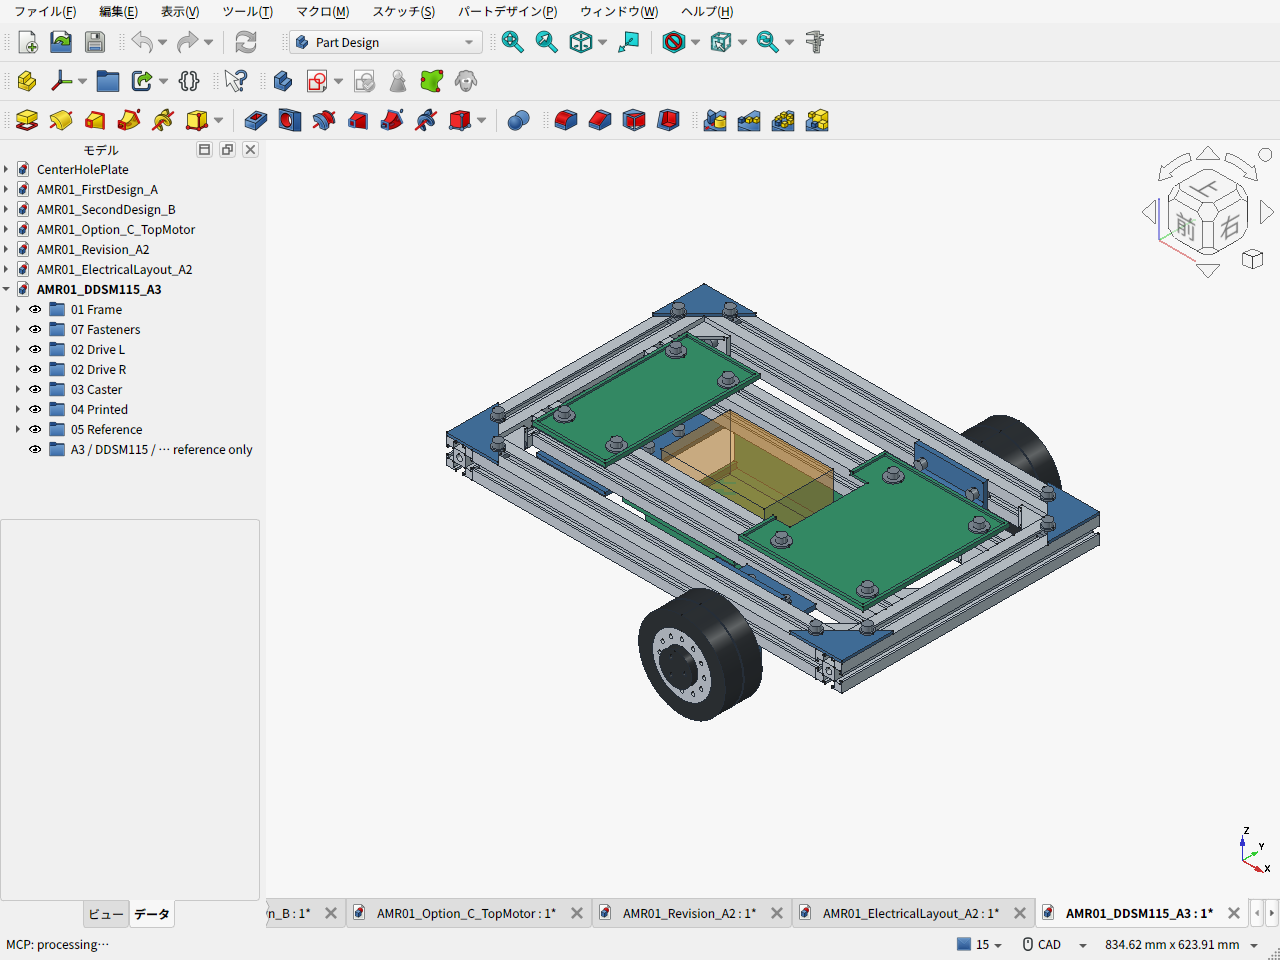
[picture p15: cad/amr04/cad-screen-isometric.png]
A3の実CAD画面


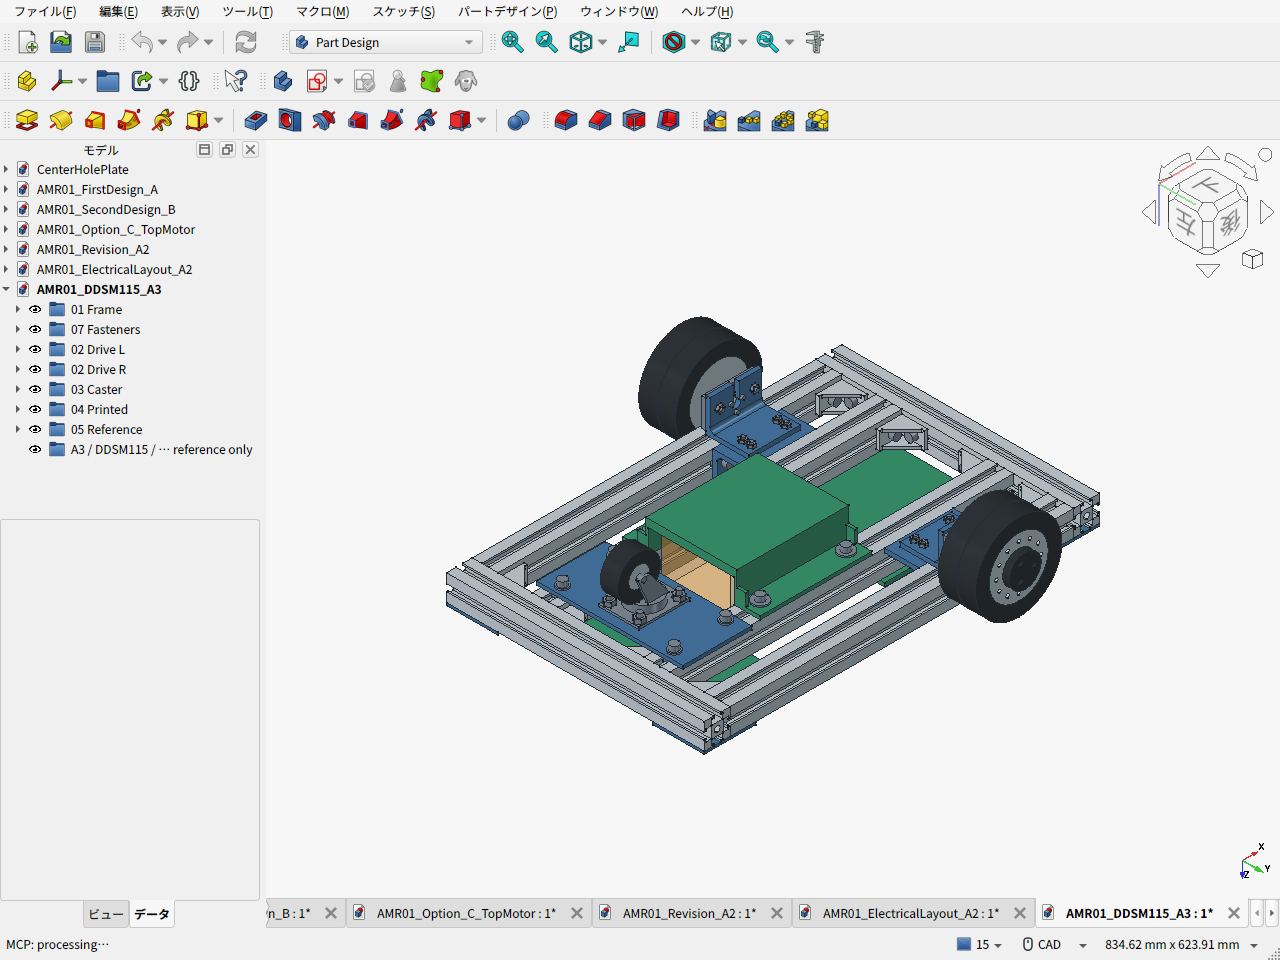
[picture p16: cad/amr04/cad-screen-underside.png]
下面の取付金具と低床電池


[駆動モジュールの拡大実画面](cad-screen-drive-module.png)

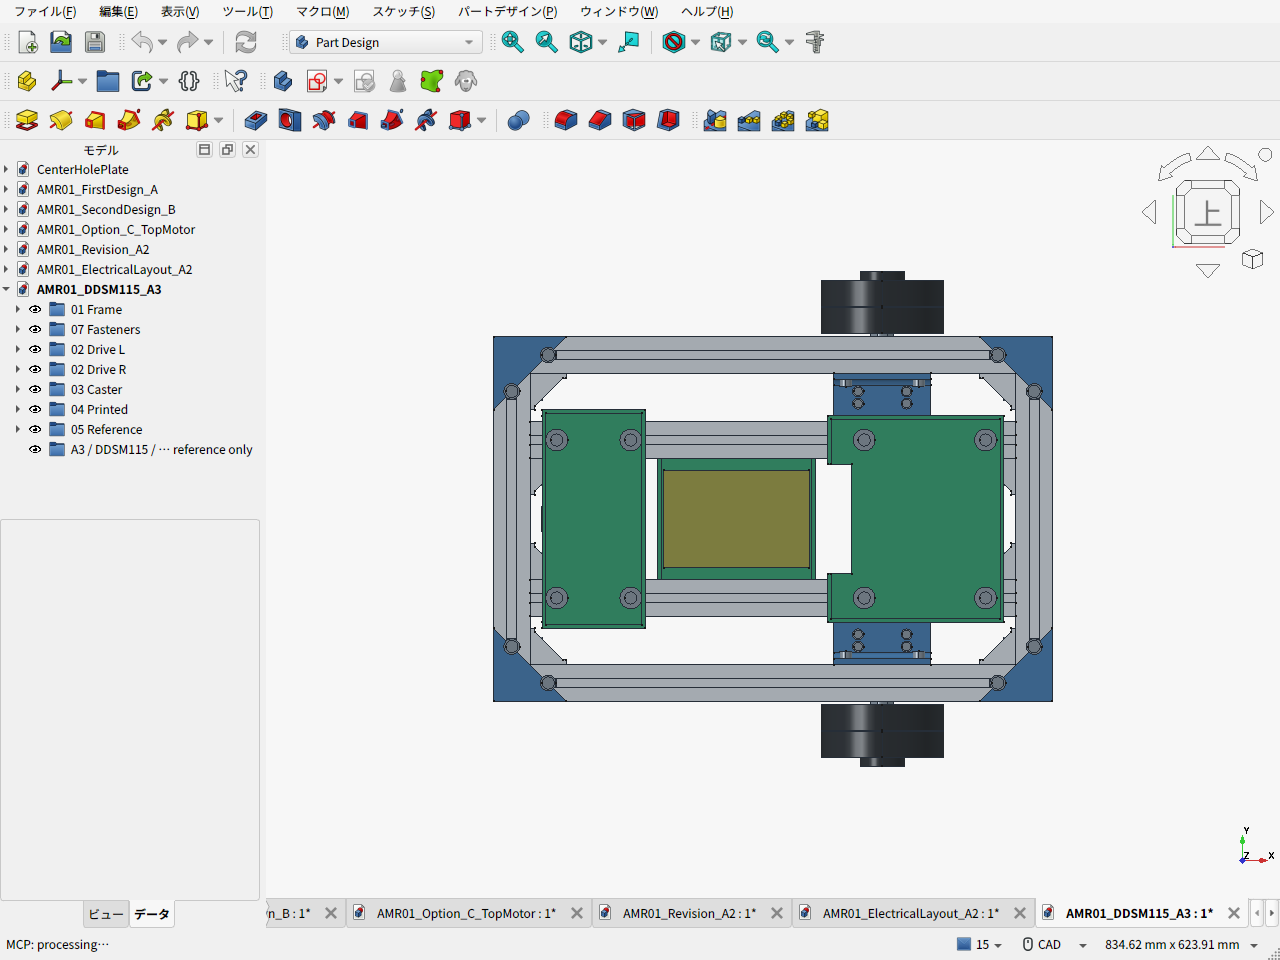
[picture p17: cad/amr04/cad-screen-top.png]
上面


## 要件と結果

| 項目 | 現行案 |
|---|---|
| 主フレーム | MISUMI NFSL6-3030、400mmを4本・300mmを2本使用。外形460×300mm |
| 接合 | MISUMI HBLFSN6-SETを8組。純正品指定だが個人向け調達経路・最終送料は未確定 |
| 駆動 | DDSM115×2、タイヤ径100.7mm・幅43mm、輪距349mm |
| 支持 | 駆動二輪＋Hammer 420G-R50自在キャスター1個 |
| 機械骨格外形 | 460×407×109.6mm。前蓋の突出込みでA2の幅394mmから13mm増 |
| 完成外形の配置目標 | 500×420×180mmへ改定。元の幅400mmでは、フレーム幅300mmとタイヤ内側3mmすきまを保ったDDSM115の前蓋が収まらない |
| 高さ | フレーム下面69mm、電池搭載面35mm、固定部最低地上高29mm |
| 質量 | 機械約4.989kg＋電池/電装仮枠2.10kg＝約7.09kg。実測前、台車上限10kg |
| 最大構成の計算 | 台車10kg＋荷物2kg＋将来アーム系2kg＝14kg。可搬実証ではない |
| PLA部品 | 電池クレードル130×160×37、後部トレイ85×180×4.4、前部トレイ145×170×4.4mm。P1S公称256mm角以内 |

### 駆動と取付理由

14kg、勾配5度、加速度0.2m/s²、転がり抵抗係数0.03を仮定すると、一輪の必要トルクは0.475N·m。比較用余裕1.5倍込みで0.713N·mとなり、DDSM115の18V公表定格0.96N·mを下回る。初期0.15m/s・角速度0.3rad/sを同時に指令した外輪は38.38rpm、将来0.3m/s・0.6rad/sでは76.75rpm。低電圧や低速連続時の温度、旋回抵抗、段差は実機確認が残る。拘束トルク2N·mを使用可能な連続値にしていない。

モーター固定面から車輪中心まで36.5mm。旧FIT0185構成の103mmに対し、外付けの継手・8mm軸・KP08軸受を撤去できる。これらを省略した分だけ材料が減る一方、DDSM115本体価格と通信部品は増える。

取付は、上下のアルミアングルt5と鋼のキー板t5を使う。キー板が固定端の三平面外形を受け、M2.5ねじ3本だけに荷重を任せない方針。キーと小ねじの実際の荷重分担は公差・締付けに依存するため、無荷重になるとは扱わない。主支持をPLAにはしない。

上側アングルは3030の内側面へM6で固定する。下側アングルとの接合はM4を4本、鋼キー板はM4を2本使用。公称形状の干渉はないが、局所肉厚・予圧維持・こじり・溝ナットの引抜き・横方向荷重を含む強度の認定は未了。粗い曲げ比較でt3よりt5を選んだ理由と限界は[独立レビュー](MOUNT_REVIEW.ja.md)に記録した。

### 加工が必要な箇所

| 材料・購入枠 | 使用形状・加工 |
|---|---|
| 40×40×t5アルミアングル、L200 | L80を2個。片脚を30mmへ切詰め、M6・M4穴 |
| 50×50×t5アルミアングル、L150 | L60を2個。片脚を40mmへ切詰め、M4・M2.5穴、中央φ10・幅7下開きスリット |
| 下角材の内R | 上側M2.5頭に干渉するR付加部だけφ5.2で局所逃げ。壁厚5mmは保持 |
| SS400 t5板 | 60×33を2枚、固定端の三平面キー輪郭とM4穴。公称片側0.05mmの嵌合すきまは加工公差の指定・検証前 |
| A5052 t4板 | キャスター取付板80×170を1枚 |
| A5052 t3板 | 60角直角三角ガセット4枚 |

市販材からの切断・穴加工・輪郭加工が必要で、組立だけでは完成しない。「外注」はこの金属加工を依頼する場合の追加費用を指す。自加工案でも工具・技能を別に要する。上下をボルトで結ぶためt5板の曲げ加工は不要だが、キー輪郭と局所逃げを未加工のまま省略しない。

### 費用

| 範囲 | A2 | A3 |
|---|---:|---:|
| 自加工の購入・材料・送料枠 | 34,519円 | **47,824円** |
| 加工外注6,000円の未見積追加枠込み | 40,519円 | **53,824円** |
| さらに10%予備費を置く場合 | — | 52,607円 / 59,207円 |

A3にはDDSM115二輪25,982円、USB-RS485B 4,400円、同店送料660円、USBケーブル500円枠を含む。A2は外付けモータードライバ・制御器を含まない旧骨格予算であり、この表は完成走行車同士の総額比較ではない。増額13,305円の内訳を[費用レビュー](COST_REVIEW.ja.md)に示す。

価格は確認価格・引継ぎ参考値・未見積仮枠が混在する。電池・充電器・主計算機・電源保護・非常停止回路・実配線/コネクター/クランプ・完成ガード・荷台・アームは別途未見積。自己作業、工具購入、印刷電気代も含まない。PLAは既所有材の消費分600円で、新規スプールが必要なら購入単位全額へ更新する。

タイヤ交換費は初期BOMに含めないが、寿命費用がゼロという意味ではない。単体調達が確認できずユニット交換が必要なら、現在の国内販売価格で一輪12,991円がかかる。[保守費の未確定事項](TIRE_WEAR.ja.md)

## 検証と再生成

機械部品203オブジェクト・全20,503ペアで公称体積干渉なし。ねじ/ナットも含み、未選定電池の予約空間を別に照合した。キャスターは5度刻み72姿勢、STEP再読込は205ソリッドで元モデルと一致、PLAの3メッシュは閉じた形状で印刷範囲内。ねじ山、公差、変形、実工具、実電池適合を保証する検査ではない。

平床の静的計算は推計7.09kgと上限10kgの台車を別ケースとして扱い、荷物/将来アームの12ケース、各キャスター720方位を評価する。台車CG=(0,0,85)mmは未測定の仮定。運搬姿勢の駆動一輪最大は約4.76kg相当で、段差衝撃やアーム動作の定格には使わない。

```sh
python3 cad/amr04/calculate_cost.py
python3 cad/amr04/calculate_design.py
python3 cad/amr04/calculate_maintenance.py
python3 -m unittest discover -s cad/amr02 -p test_calculate_design.py -v
```

FreeCAD GUIのPython実行環境で、順に以下の各ファイルを実行する。`__file__`を対象パスとして渡す。

1. `build_chassis.py` — FCStd・STEP・STLを作成。
2. `validate_chassis.py` — 干渉・質量・STL・STEPを検査し`fasteners.csv`を生成。
3. `capture_screens.py` — FreeCADの実ウィンドウとビューポートを保存。
4. `build_electrical_layout.py` — 予約機器・配線・整備空間を別文書へ作成・検査。
5. `capture_electrical_layout.py` — 電装配置の実画面を保存。

過去案は[第一案A](../amr01/README.ja.md)、[第二案Bと却下したベルト案C](../amr02/README.ja.md)、[第一案改A2](../amr03/README.ja.md)に保存する。

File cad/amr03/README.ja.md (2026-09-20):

# 第一案改 A2：スペーサー撤去と低い電池配置

> このA2は比較履歴です。現行CADは[DDSM115のA3](../amr04/README.ja.md)。

2026-09-20 / v0.6.0。**第一案Aを基に、駆動部の40mmスペーサー8本とキャスター側の6mmスペーサー4本を撤去した。** KP08を上下反転して支持板を3030の下面へ直接固定する。100mm輪・同軸駆動・3030定尺300/400mmを維持し、ベルト案Cは却下、箱形支持の第二案Bも現行案から外す。

狙いは第一案の簡素さと費用を保ち、搭載物を低く置くこと。フレームを6mm下げ、電池用PLAクレードルをフレーム内へ設けた。**40mmスペーサーの撤去が、そのまま40mmの車体下降になる構成ではない。**

**追記：** [電池位置・配線・交換空間の検討CAD](ELECTRICAL_PACKAGING.ja.md)を追加した。駆動系は[実機採用例を起点に再選定](DRIVE_RESELECTION.ja.md)し、DDSM115一体ホイールを次の取付検討の優先候補とする。以下の骨格CAD・費用はFIT0185構成の比較基準で、新駆動系へ変更済みではない。

## 実際のFreeCAD画面とデータ

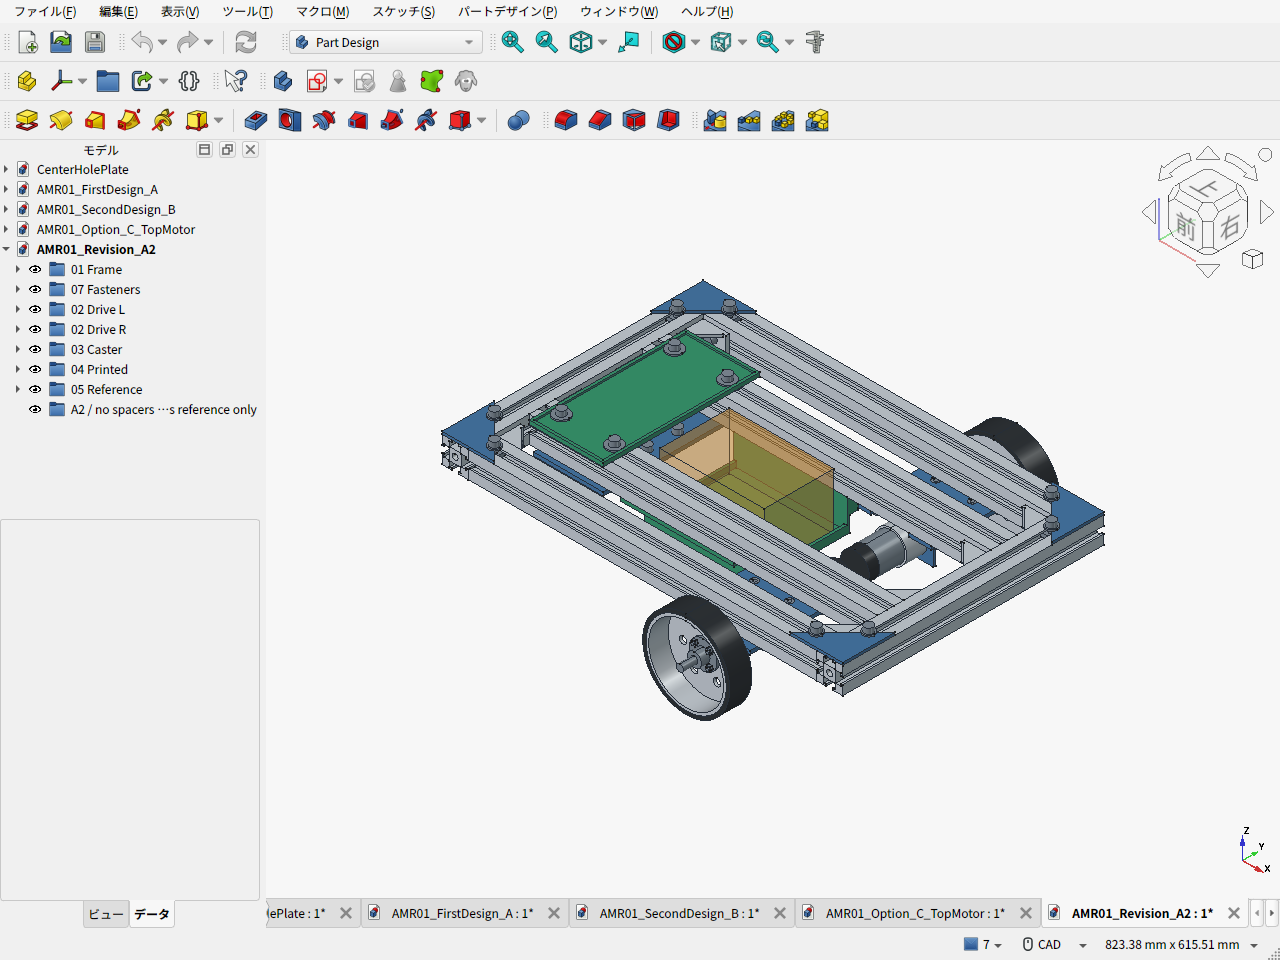
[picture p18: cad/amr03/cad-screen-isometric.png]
第一案改A2：FreeCAD実画面


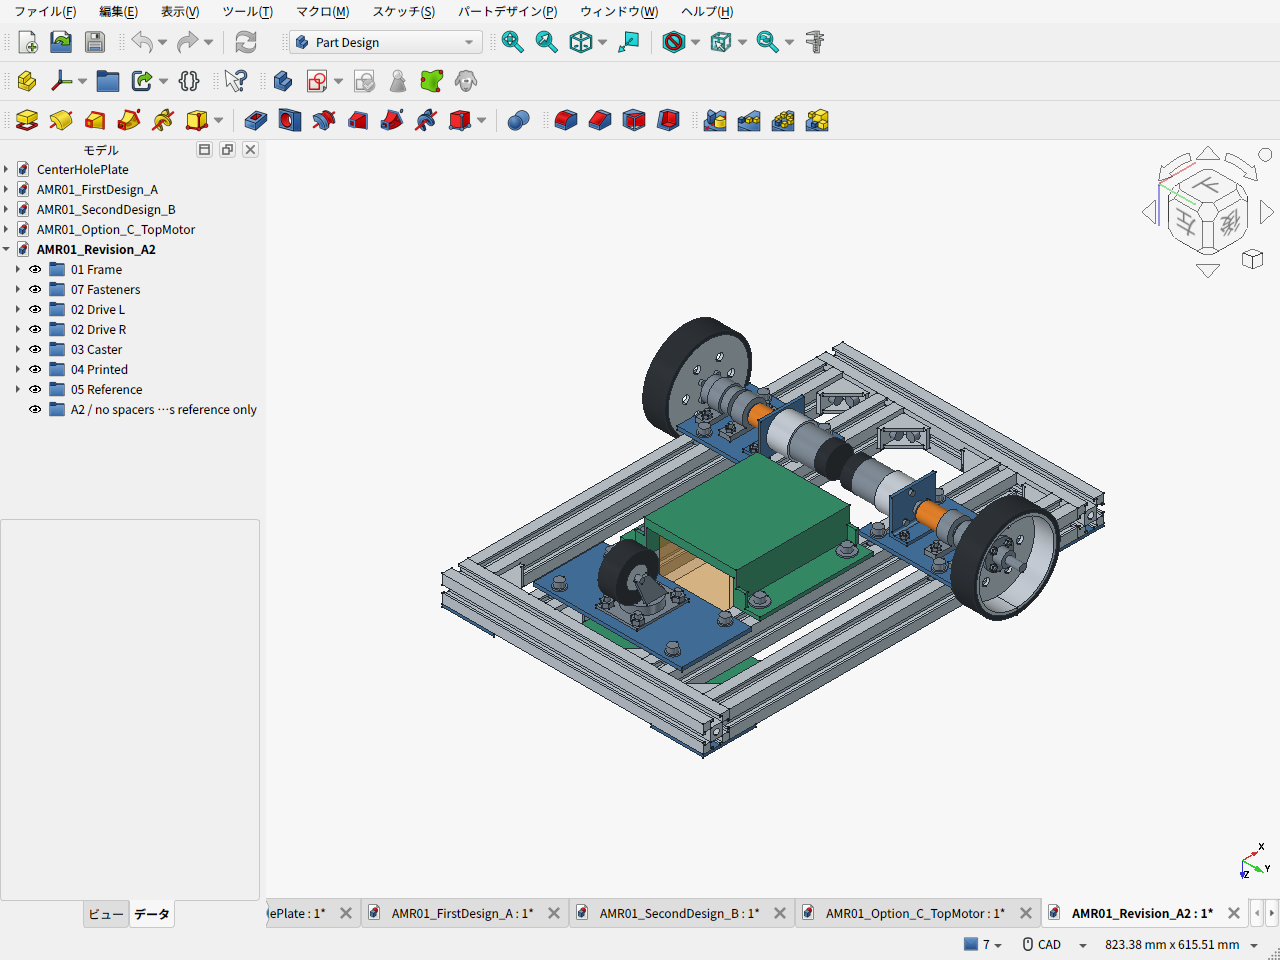
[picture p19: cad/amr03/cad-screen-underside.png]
スペーサーを撤去した支持部：FreeCAD下面画面


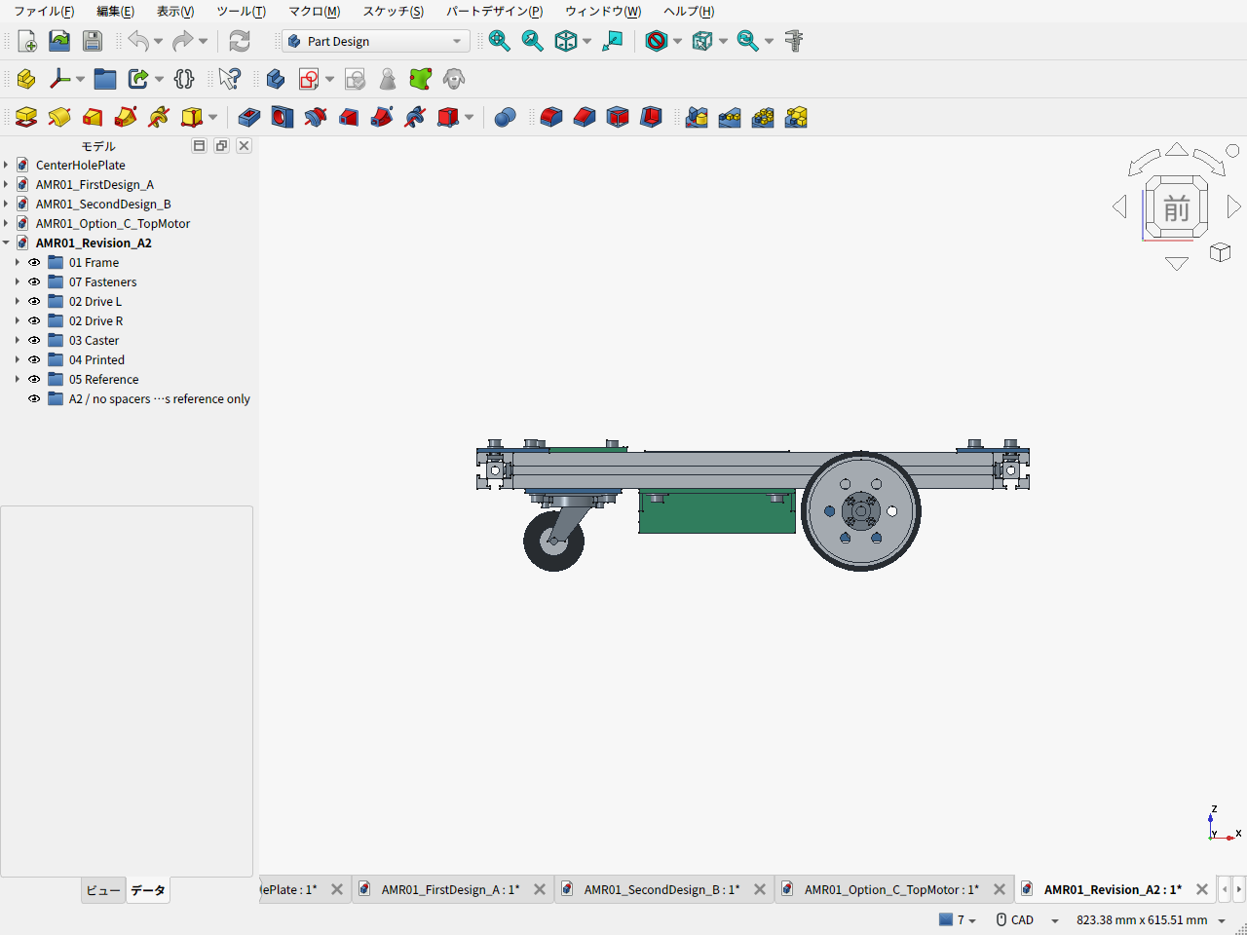
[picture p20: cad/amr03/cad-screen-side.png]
第一案改A2：側面の高さ関係


茶色の半透明箱は未選定電池の予約空間120×80×65mm。購入済みの電池や重量保証を表すものではない。緑がPLA部品、青が加工する金属部品。

- [FreeCAD本体](AMR01_Revision_A2.FCStd) / [STEP](AMR01_Revision_A2.step) / [上面の実画面](cad-screen-top.png)
- [部品表](BOM.csv) / [購入URL・価格区分](bom.json) / [費用集計と第一案との差額](cost_summary.json)
- [CADから集計した締結部品](fasteners.csv) / [CAD検証・重量](validation_results.json)
- [設計条件](design_parameters.json) / [駆動・軸・重心感度計算](calculation_results.json)
- [実機採用例からの駆動系再選定](DRIVE_RESELECTION.ja.md) / [従来のモーター候補比較](MOTOR_SELECTION.ja.md)
- [車輪担当の検討](WHEEL_REVIEW.ja.md) / [低重心化の独立レビュー](CG_REVIEW.ja.md) / [150mm輪の調達検討・今回は不採用](wheel-shopping-notes.ja.md)
- 印刷用STL：[電池クレードル](BatteryCradlePLA.stl) / [電装トレイ](ElectronicsTrayPLA.stl)

## 変更点と設計理由

| 項目 | 第一案A | 第一案改A2 |
|---|---|---|
| 3030フレーム | 外寸460×300、400mm材4本＋300mm材2本 | 同じ定尺・本数 |
| フレーム下面／上面 | 床から75／105mm | **69／99mm：6mm低下** |
| 駆動輪 | 径100、幅25.4、輪距354mm | 維持 |
| KP08軸受 | 支持板の上に置く | 支持板の下で上下反転 |
| 軸受支持板 | z=31〜35mm、40mmスペーサーで吊る | z=65〜69mm、フレームへ直接固定 |
| キャスター支持板 | z=65〜69mm、6mmスペーサー付き | 同じ高さでフレームへ直接固定 |
| モーター | 下置き、ケース中心z=50mm | 下置き、偏心を45度回し中心z=45.05mm |
| 電池搭載面 | 上トレイ上面z=107mmを仮定 | **クレードル床上面z=35mm** |
| フレーム接合 | 汎用金具セット | MISUMI HBLFSN6-SET×8、純正溝ナット計44個 |
| 骨格の外形 | 460×394×115.6mm | **460×394×109.6mm** |

車軸は床上50mm、KP08の軸心から取付面までは仮寸法15mm。反転すると取付面が床上65mmになり、t4支持板を介してフレーム下面69mmへ直結できる。これでキャスターも同じ高さのまま直結でき、長い支持柱が不要になる。100mm輪のまま従来の配置を40mm下げるだけでは、車軸・モーターとレールが重なる。

モーターの出力軸中心はx=90/z=50mmで維持する。ケースの偏心7mmを45度回し、ケース中心をx=85.05/z=45.05mmへ移した。ケースとフレームの公称隙間は5.45mm。90度回すとケースが地上高25mmの設計目標を割るため、45度を選ぶ。モーター金具は第一案と同じ40×20×t3アングルを反転し、PCD31の固定穴も回転後の15/135/255度へ移している。

150mm輪ならフレームをさらに下げる配置は可能だが、同じ駆動力で必要トルクが1.5倍になり、ハブ・キャスター周辺の変更が増える。今回は第一案の足回りを維持して具体化した。ベルト案の再検討は行わない。

## 重量と重心の扱い

骨格概算**4.63kg**＋電池・電装等の枠2.05kg＝**約6.68kg**。自重上限10kgまで約3.32kg。購入品の公称・参考質量と加工部品のCAD体積を合わせた推計で、実測ではない。荷物2kgと将来アーム系2kgは別枠、最大14kgで駆動を計算する。

電池・アダプター0.75kgの枠を、同じ高さ65mmの箱として旧トレイ上から新クレードルへ移す仮定では、その中心高さは139.5→67.5mmとなる。**72mm下がるのは電池の仮中心で、機体全体の重心ではない。** 他を同じにした感度計算では、電池移動だけの全体重心への寄与は総質量6.68kgで約8.08mm低下、10kgなら5.40mm低下。

フレーム1.672kgの6mm低下は別に約1.50mm／1.00mmの寄与を持つ。ただし、支持板は上がり、スペーサー等の質量も変わるため、これらの和を実機A→A2の全体重心差とは扱わない。電池・電装・荷台の現物配置が決まってから全体重心を更新する。平らな床での静的な支持余裕は重心の水平位置で決まり、高さを下げただけでは増えない。

電池を避けて後方に85×180×4.4mmの電装トレイを置く。電池クレードルは130×160×37mm。両方とも[P1S公式の256mm立方の造形範囲](https://us.store.bambulab.com/products/p1s)に収まり、PLAを中実として約174g、支持材等込みの予算は250g以内を仮置きする。クレードル上部の張出しにはサポート等が必要で、印刷条件はスライサーで確認する。

PLAクレードルは電池荷重を受ける暫定支持部品。大径ワッシャを使うが、底・フランジのクリープや熱の影響は未検証。3030へ固定するストラップ2本を費用・質量枠に入れたものの、製品と取回しは未選定でCADには含めていない。ストラップを加えてもPLA床のクリープがなくなるとは扱わない。主車輪の支持板・金具は金属を維持する。

## 費用

第一案と同じ購入単位を基準にする。候補品は未発注。価格区分は、第一案の同日確認価格を引継ぐもの、メーカー参考価格、未見積の予算枠を区別した。

| 機械骨格の費用 | 第一案A | 第一案改A2 | 差額 |
|---|---:|---:|---:|
| 自加工：部品・材料・送料 | 34,159円 | **34,519円** | +360円 |
| 加工外注の仮枠込み | 40,159円 | **40,519円** | +360円 |

スペーサー素材と金属トレイの削減に対し、純正金具・追加ナット、PLA消費、ストラップ、締結材と送料を加えた結果。詳細は[差額内訳](cost_summary.json)。自加工34,519円は部品・消費材料30,169円＋送料枠4,350円。10%予備費は別枠で、自加工37,971円、外注込み44,571円となる。

外注6,000円は金属部品の切断・穴あけ・皿もみ等を依頼する場合の未見積枠で、必要な購入部品ではない。自加工するなら加算しない。工具を所有している前提で、工具購入費と自己作業時間は含まない。**電池・電装・ドライバ・制御基板・センサー・非常停止回路・完成用ガード・荷台・アームは別途。** 純正HBLFSN6-SETは指定したが、個人向け購入経路と送料は未確定なので購入確定額とは扱わない。

## 足回りの選定と組立

| 部品 | 採用候補と理由 |
|---|---|
| モーター | DFRobot FIT0185×2。第一案を流用、12V・131:1・無負荷83rpm、205g/個。連続定格は未確認 |
| 駆動輪 | Amazon B0B23WBLBK、100×25.4mm・穴8mm。第一案を流用し必要トルクを増やさない |
| 車輪軸／軸受 | 8×100mm軸×2、KP08×4。各車輪の荷重を独立軸で受ける |
| ハブ／継手 | 第一案の穴8mmハブと6→8mmジョーカップリング。車輪側の穴加工が必要 |
| キャスター | Hammer 420G-R50。高さ65mm、第一案と同じ接地位置 |
| 接合金具 | HBLFSN6-SET×8。付属M6ねじ／HNTT6-6各16個、溝ナット追加28個 |

軸受用M4×16皿ねじ8本とモーター金具用M4×12皿ねじ4本は支持板上面へ埋める。反対側にM4ナットを置き、板上面がレールへ直接接触できるようにした。固定M6も旧スペーサー用の長さを残さず選び直している。

基本の組立順は、溝ナットを入れる→フレームを組む→支持板へ軸受・モーター金具を皿ねじで固定する→車軸の芯と手回しを確認する→支持板ごとフレーム下面へ取り付ける。レールに隠れる皿ねじがあるため、フレームへ固定してから全ねじを締める前提にはしない。純正金具はメーカー指定のねじ挿入順に従う。

車輪中心y=177mm、軸受中心y=118/145mmを維持するので、**32mmの車輪張出しは第一案と同じ**。比較用100N荷重で最大軸受反力218.5N、8mm軸の曲げ応力63.7MPaも同じで、スペーサー撤去による改善とは主張しない。反転したKP08の保持能力、板の曲げ、ねじの引張・締結、溝接合の滑りは現物仕様を確認する。

14kg・加速度0.2m/s²・5度・転がり抵抗係数0.03・余裕1.5の計算では、一輪0.708N·mが必要。FIT0185の4.41N·mは拘束トルクで連続定格ではない。初期0.15m/s＋0.3rad/sは外輪38.8rpm。暫定指令上限65rpmに対し、0.3m/s＋0.6rad/sは77.6rpmとなるため同時指令を制限する。

## CADで確認した範囲

- 実部品形状226個、別に電池の予約空間1個。全形状が有効。
- ねじ・ナットを含む実部品25,425組で、0.001mm³超の公称形状干渉なし。電池予約空間との干渉もなし。
- 支持板・キャスター板とフレームの接触、スペーサー0本、3輪の接地、最低固定部地上高25mmを確認。
- キャスターを5度刻み72方位で回して固定部との干渉なし。
- 必要溝ナット44個をCADとBOMで照合。STEP再読込の228ソリッドと体積一致、STLの閉鎖性と造形範囲を確認。

公称モデルでの確認であり、部品定格・公差・工具アクセス・変形を保証するものではない。特にKP08実寸、反転時の取付、車輪ウェブとハブ穴、モーター金具の隅RとM3工具アクセス、カラーとハブねじ頭の0.8mm隙間、皿頭規格、電池配線・保持を現物で詰める。モーター金具の内R3は今回CADへ含めた。幅394mmに対し完成目標400mmでは側面ガードの余裕が片側3mmしかなく、ガード形状も残る確認事項。

## 再生成

通常のPythonで費用・計算を更新する。設計計算は既存の`cad/amr02/calculate_design.py`の共通計算関数を再利用する。

```sh
python3 cad/amr03/calculate_cost.py
python3 cad/amr03/calculate_design.py
python3 -m unittest discover -s cad/amr02 -p 'test_calculate_design.py' -v
```

FreeCADのPythonコンソールでは、パスを配置先へ置き換える。

```python
for filename in ('build_chassis.py', 'validate_chassis.py', 'capture_screens.py'):
    p = '/path/to/amr-pj/cad/amr03/' + filename
    exec(compile(open(p).read(), p, 'exec'), {'__file__': p})
```

寸法の一部は[再生成コード](build_chassis.py)に定義している。寸法を変えるだけで各部の成立を自動解決する拘束アセンブリではない。変更後は部品配置・穴・公差と費用を一緒に見直す。

## 主な一次資料

- [DFRobot FIT0185](https://wiki.dfrobot.com/fit0185/) / [メーカー共通寸法図](https://www.dfrobot.com.cn/image/data/FIT0186/GB37Y3530-251R-dimensions.jpg)
- [MISUMI HBLFSN6](https://jp.misumi-ec.com/vona2/detail/110300442340/)
- [Hammer 420G-R50公式カタログ](https://www.hammer-caster.co.jp/common/pdf/company/CTLG_420GR_s44_06.pdf)
- 購入候補のURLと価格記録は[BOM元データ](bom.json)。第三者の商品写真・寸法図そのものは転載していない。

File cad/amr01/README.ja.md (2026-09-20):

# AMR-01 第一案 A — 3030フレームの機械骨格

現行案は[第一案改A2：スペーサー撤去と低い電池配置](../amr03/README.ja.md)。このページは元の第一案Aの比較基準を保存している。

2026-09-20 / FreeCAD 1.1.3 / 形状v0.4.0・重量条件v0.4.1。**部品を選定して組付けを検討する第一案。購入品の未公開寸法、連続運転、実測重量は未確認で、製作図の確定版ではない。**

フレームはユーザー指定のAmazon定尺、300mm・400mmの3030を使用する。外寸460×300mm、400mm材4本・300mm材2本。追加の減速ベルトを使わず、左右のFIT0185からカップリングで独立した8mm車輪軸を駆動する。各軸をKP08で2点支持し、荷重を取付板・4本のスペーサから内外の長手フレームへ伝える。外周4隅はt3ガセットを追加する。

## 実際のCAD画面

FreeCADで実モデルを開いた画面のキャプチャ。画像生成による完成予想図ではない。

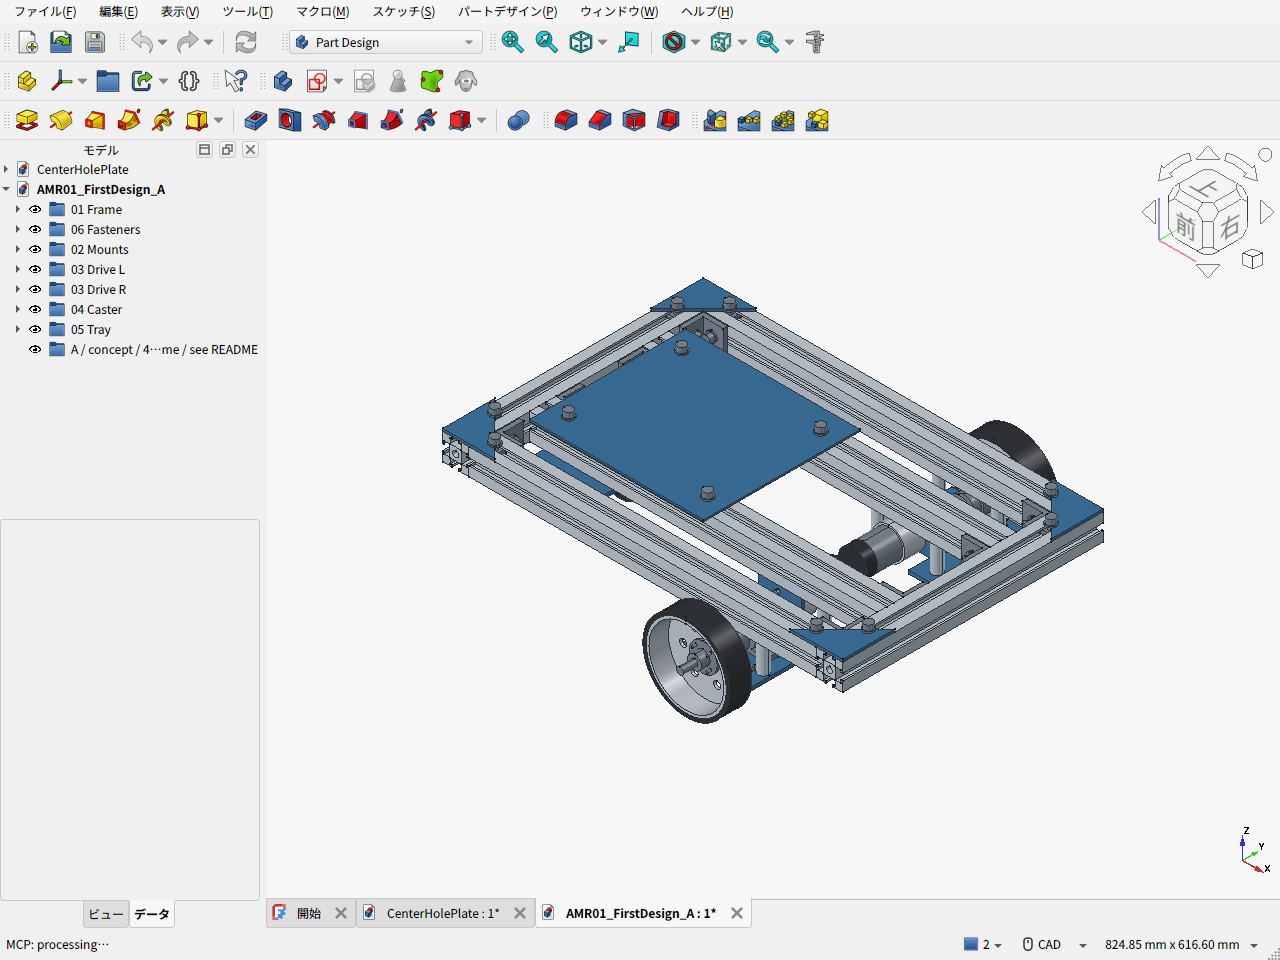
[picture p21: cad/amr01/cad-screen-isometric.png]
FreeCAD 第一案 A 全体


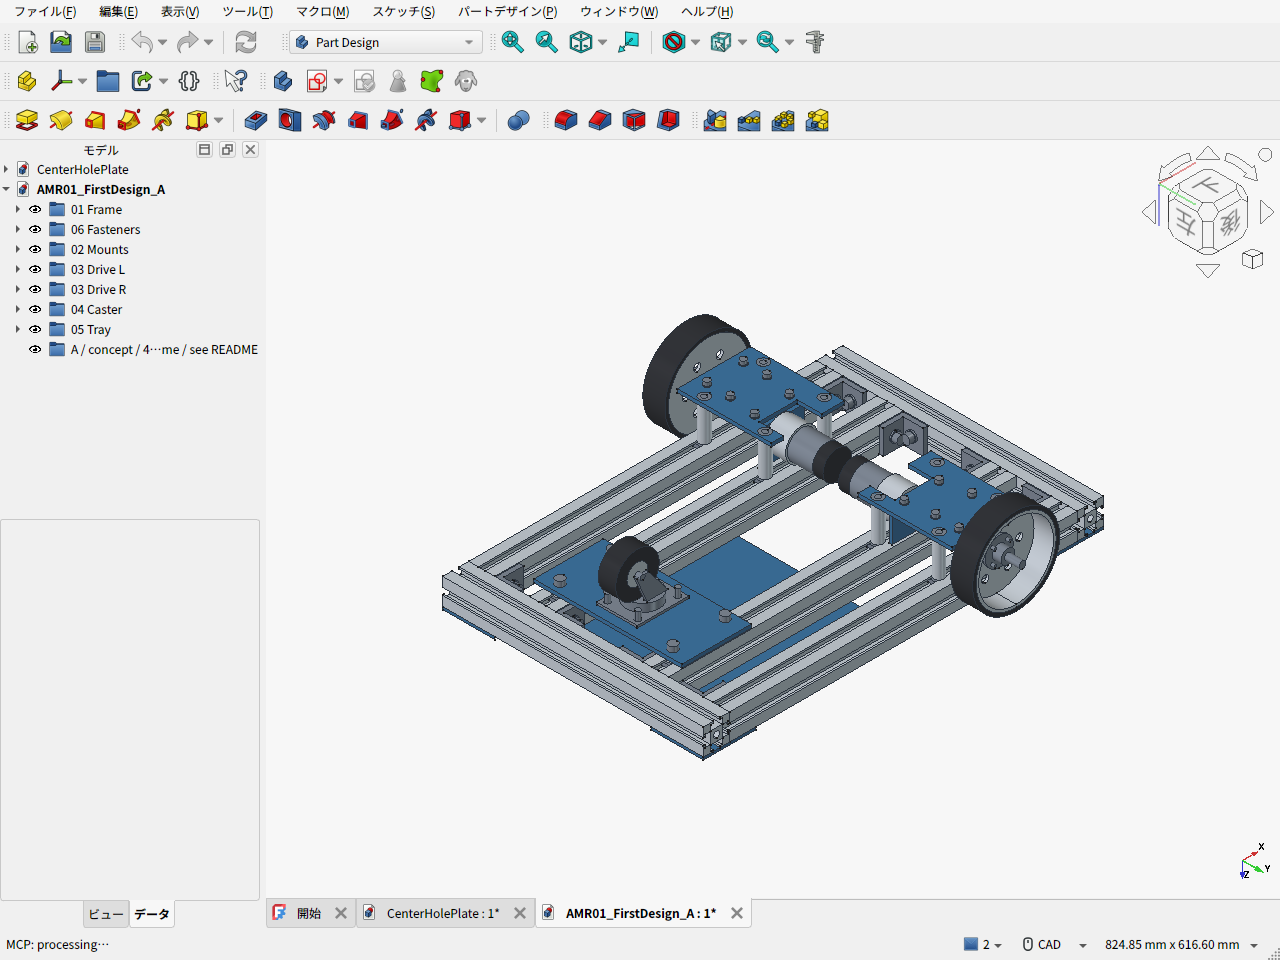
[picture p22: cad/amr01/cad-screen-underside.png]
FreeCAD 第一案 A 底面側


- [編集可能なFreeCADファイル](AMR01_FirstDesign_A.FCStd)
- [STEP](AMR01_FirstDesign_A.step)
- [再生成コード](build_chassis.py) / [機構パラメータ・未確認項目](mechanical_parameters.json)
- [部品表 CSV](BOM.csv) / [元データ・購入URL・確認日](bom.json) / [必要ねじ一覧](fasteners.csv)
- [検証結果](validation_results.json) / [検証コード](validate_chassis.py)

## 費用

税込・2026-09-20確認。使用した本数だけの按分ではなく、**予備やパックの余りも含む購入額**を計上した。発注はしていない。

| 項目 | 金額 |
|---|---:|
| 3030フレーム：300mm・400mm 各4本組 | 3,419円 |
| コーナー金具20個・M6ナット等のセット | 2,580円 |
| FIT0185モーター2個 | 6,039円 |
| 100mm駆動輪2個 | 5,210円 |
| ハブ・軸・KP08・カップリング・軸カラー | 6,788円 |
| 420G-R50キャスター1個 | 373円 |
| **確認済み商品の小計** | **24,409円** |
| 板材・アングル・スペーサ素材の予算 | 4,100円 |
| 追加ねじ・ナット・ワッシャの予算 | 1,800円 |
| 送料の予算（本州配送を仮定） | 3,850円 |
| **自分で加工する場合の現金支出目安** | **34,159円** |
| 切断・穴あけ等の外注追加枠 | +6,000円 |
| **外注加工を含む目安** | **40,159円** |

価格確認済みと予算枠は[BOM](bom.json)の`price_kind`で区別する。予備費10%込みなら自加工約3.8万円、外注約4.5万円を見込む。板材・加工の正式見積は未取得で、通販送料も住所・注文の組み合わせによって変わる。工具を既に持っている自加工ケースには、自分の作業時間と新規工具購入代を含めない。

**これは機械骨格の費用。電池、モータードライバ、制御基板、センサー、非常停止回路、機能ガード、アームは含まない。走行可能な完成機の総額ではない。**

コストを抑えるため、全面4040化・追加の外部減速機・装飾外装は採用しない。比較したFIT0403は2個で10,615円、FIT0185より商品代で4,576円高い。FIT0403側が送料無料になる場合、送料込みの差は約2,376円まで縮まる。第一案は低速試験を優先してFIT0185を選んだ。再選定時は単価だけでなく加工・送料を含めて比較する。

## 選定と配置

| 部品 | 第一案の仕様・位置 |
|---|---|
| モーター | DFRobot FIT0185 ×2、12V、131:1、無負荷83rpm、エンコーダ付き、メーカー公称205g/個 |
| 車輪 | Amazon B0B23WBLBK ×2、直径100mm・幅25.4mm・穴8mm、金属ホイール＋ネオプレン、販売者記載約300g/個 |
| 車輪ハブ | uxcell B07PTPFX35、穴8・H13・フランジ32・PCD24。車輪に合わせた取付穴加工が必要 |
| 支持軸・軸受 | C45クロムメッキ8×100mm ×2、KP08 ×4。モーター出力軸に車重を直接負担させない |
| 継手 | 6→8mm、外径20×長25のジョーカップリング ×2 |
| キャスター | ハンマー420G-R50。高さ65、座59×47、穴ピッチ46×35、トレール16、メーカー許容荷重300N |
| フレーム高さ | 床から下面75、上面105mm |
| 駆動輪中心 | x=90、y=±177、z=50mm。輪距354mm |
| 後方キャスター | 旋回軸x=-150、y=0。図では車輪軸x=-166、z=25 |
| 機械骨格の包絡 | 約460×394×115.6mm。現物差・ガード・配線・電装は含まない |

従来の輪距350mmから各輪を2mm外へ移し、ハブ取付ねじ頭と軸カラーの公称隙間0.8mmを確保した。0.8mmは現物公差を吸収する保証値ではなく、実測で再確認する箇所。軸は切らずに100mmのまま使用し、両軸端を含め幅394mm。完成時500×400mmの目標に対し、側面の軸端ガードの余地は片側3mmしかなく、ガード方式は要再検討。

CADの青色部品は加工するアルミ材。2枚の車輪支持板、2個のモーターアングル、キャスター取付板、4枚のガセット、機器トレイをモデル化している。ねじ・溝ナットの主要位置も表示。ねじ山、六角穴、一部のナット・ワッシャ・止めねじは省略した。

## 駆動性能の扱い

FIT0185の45kgf·cm（約4.41N·m）は**拘束トルク**で、連続定格ではない。連続トルクはメーカー公表値を確認できていない。従来の「0.8〜1N·m、負荷時80rpm」という探索目標を満たした製品とは扱わない。

- 初期目標0.15m/s・0.3rad/sの同時指令では外輪38.8rpm。
- 第一案の各輪指令上限を暫定65rpmとする。これは制御上限であり、負荷時に保証された性能ではない。
- 0.3m/s・0.6rad/sを同時に出すには外輪77.6rpmで、この案の指令上限を超える。`|v| + 0.177 |ω| ≤ 0.3403 m/s`として組合せを制限する。0.3m/s時の旋回上限は約0.228rad/s。
- 総質量14kg・5度の計算における余裕込み0.708N·mを、無負荷点と拘束点の直線補間に当てはめると約69.7rpm・1.42A。これは選定の粗い見当で、連続運転・温度・低電圧性能の保証ではない。

まず水平な硬い床の低速試験用。モータードライバの電流制限を設け、温度・電流・実回転数・継手の滑りを測定する。段差・坂道・アーム操作の運転条件はこのCADでは確定していない。

## 自重上限10kgと現案の見込み

メーカー・販売者の公称質量と、加工板等のCAD体積からの概算を合わせると、**骨格約4.73kg**。従来の電池・電装・計算機・配線/ガードの予算2.05kgを加えると**約6.78kg**で、台車自重上限10kgに対して約3.22kgの余裕がある。

ユーザーの指定により6kg目標を撤回し、電池・電装込み10kg以内とした。約6.78kgは現案の概算で、10kgまで重量を増やす目標ではない。未選定の保持機構、補強、電装変更は残りの枠で管理する。軽量化だけを目的とした費用増は優先しない。静的計算に6.78kg・10kgの質量ケースを追加したが、重心位置は実測ではない。

## 寸法と実部品の確認が必要な点

1. モーター図面はメーカーがFIT0185からリンクする共通図。減速部L24mm・エンコーダ長12mmでモデル化したが、中国語注記ではエンコーダ10mmとも読め、減速比でLが変わると記載される。131:1現物の長さと配線突出を確認する。軸径6、偏心7、PCD31、M3固定は同図に基づく。M3×5をt3台座に使い、ねじ込みは2mm（メーカー本文の最大3mm以内）。
2. 車輪の外径・幅・穴径以外は簡略形状。ウェブをt3と仮置きし、ハブのPCD24・4穴を45度ずらして設計した。既存穴の位置、肉厚、凹部の奥行き、穴径を実測してから加工する。既存穴と干渉する場合は穴の位相・取付方式を修正する。
3. KP08の軸心高15mm、PCD42mmと足厚を実測する。安価な軸受の型名だけでは寸法公差と許容荷重の保証にならない。
4. 3030金具セットのナットがミスミ6シリーズの溝に適合するか、ボルトが底突きせず十分ねじ込めるかを確認する。CADの押出断面はT溝の概略であり、メーカー金型断面の複製ではない。
5. 車輪、ハブ、カップリングの連続トルク・輪荷重の仕様は不足している。初期受入試験で確認し、未検証のまま2kg可搬を認定しない。

## 実施した確認

217個の形状の妥当性、主要67部品の2,211組の公称形状干渉、フレーム外寸、3輪の床面接触、駆動系固定部の最低地上高26.2mm、車輪のねじ頭とカラーの隙間、CADとBOMの使用数、M6溝ナット40個を確認した。

ねじを除く公称モデルの干渉検査であり、全ねじ締結の強度、現物公差、キャスター全旋回の厳密干渉、ガード、ケーブル、たわみ、耐久・実機制動を検証した結果ではない。重量の概算判定は`estimated_base_within_upper_budget: true`。完成実機の測定結果ではない。

再生成はFreeCADのPythonコンソールで、リポジトリ内の実パスに置き換えて実行する。

```python
p = '/path/to/amr-pj/cad/amr01/build_chassis.py'
exec(compile(open(p).read(), p, 'exec'), {'__file__': p})
p = '/path/to/amr-pj/cad/amr01/validate_chassis.py'
exec(compile(open(p).read(), p, 'exec'), {'__file__': p})
```

部品位置の大半は`build_chassis.py`内の寸法で定義し、輪距は設計パラメータから読む。自由な寸法変更を自動解決するアセンブリ拘束モデルではない。変更時は配置・穴・部品選定も合わせて修正する。

費用の再集計は通常のPythonで`python3 cad/amr01/calculate_cost.py`。画面保存はFreeCAD内で[capture_screens.py](capture_screens.py)を実行する。

## 主な根拠

- [DFRobot FIT0185 仕様](https://wiki.dfrobot.com/fit0185/) / [メーカーの製品ページと共通寸法図へのリンク](https://www.dfrobot.com.cn/goods-706.html) / [共通寸法図](https://www.dfrobot.com.cn/image/data/FIT0186/GB37Y3530-251R-dimensions.jpg)
- [FIT0185国内購入価格](https://www.digikey.jp/ja/products/detail/dfrobot/FIT0185/6588527) / [FIT0403比較価格](https://www.digikey.jp/ja/products/detail/dfrobot/FIT0403/6588578)
- [ハンマー公式カタログ](https://www.hammer-caster.co.jp/common/pdf/company/CTLG_420GR_s44_06.pdf) / [420G-R50販売価格・寸法・送料](https://www.tanaka-km.com/view/item/000000036665)
- [KP08寸法の比較用供給元](https://www.motedis.es/en/Pillow-blocks-8mm-KP08)。採用Amazon品の寸法画像も照合した。
- Amazon購入品のURLは[BOM](bom.json)に記載。商品名・選択ASIN・価格・注文ボタンをページ取得で確認。第三者の商品写真や図面そのものはリポジトリへ複製していない。

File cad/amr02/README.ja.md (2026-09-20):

# 第二案 B：下置き同軸駆動と内外軸受の箱形支持

**比較履歴：この案は現行設計ではない。** ユーザーの指示でベルト案Cは却下、Bも現行案から外した。現在は[第一案改A2：スペーサー撤去と低い電池配置](../amr03/README.ja.md)へ進めている。以下は検討時点の記録。

2026-09-20 / v0.5.0。**下置きのまま車輪の支持方法を変える第二案**と、上置きベルト駆動の比較配置Cを作成した。第一案の下置きを不適切と判断したものではない。三担当で要求・車輪支持・上置き配置を検討し、改善効果と増費を分けて比較している。

第二案は3030の300/400mm定尺、フレーム高さ、モーター、100mm車輪、50mmキャスターを維持する。車輪の両側に軸受を置き、40mmの丸スペーサ8本に代えて金属板と角金具で荷重をフレームへ伝える。**費用は第一案より上がるため、第二案を無条件の最終採用とはしていない。** 購入品の実寸・荷重定格、加工見積、現物試験が残る比較試作設計である。

## 実CAD画面とデータ

以下はFreeCADの実画面。下面図は車体を裏側から見ている。

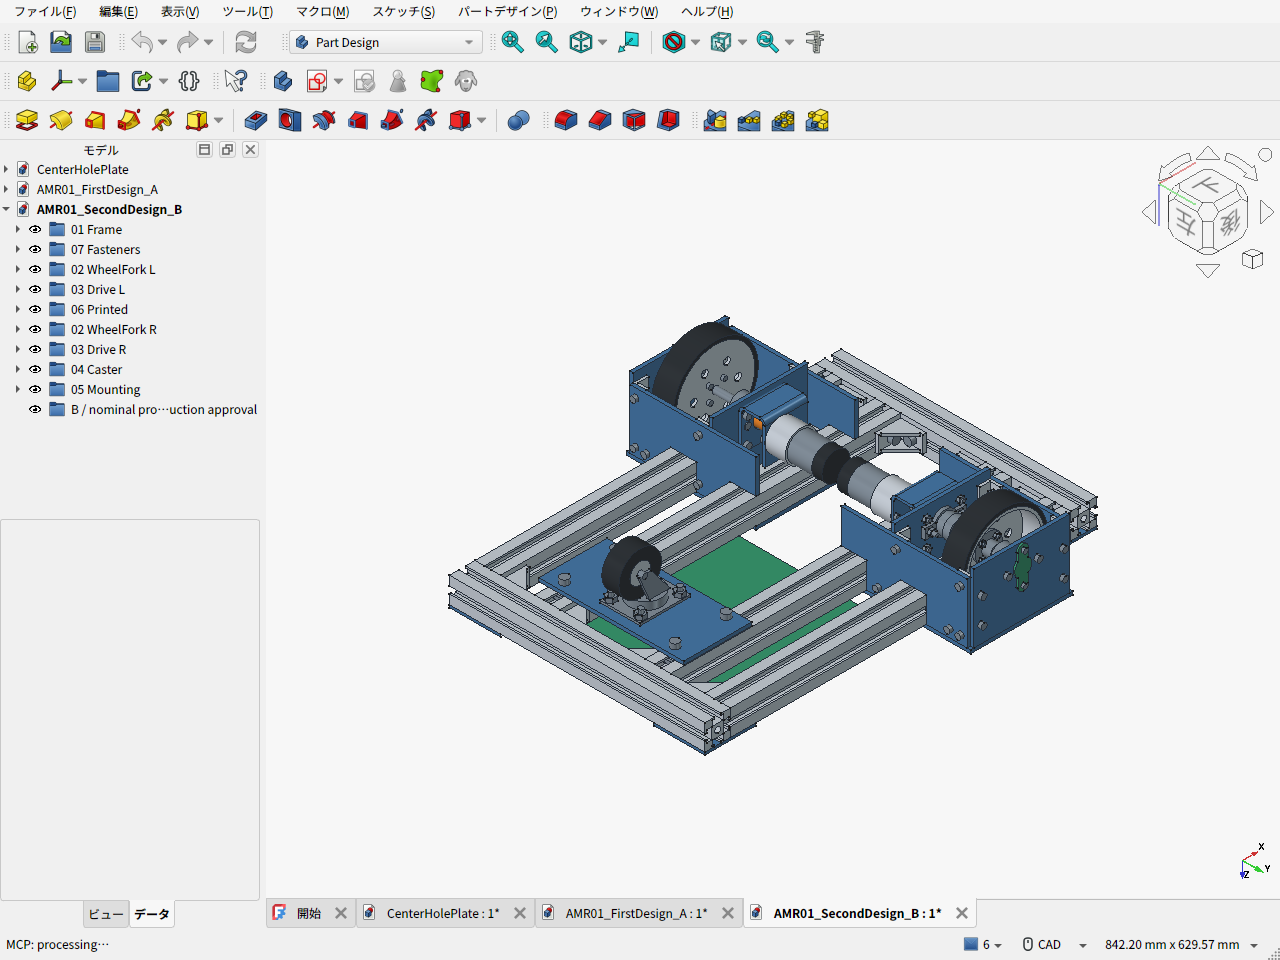
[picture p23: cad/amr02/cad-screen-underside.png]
第二案B：FreeCAD実画面・下面


- [通常の斜視画面](cad-screen-isometric.png) / [上面](cad-screen-top.png) / [支持板を半透明にした画面](cad-screen-drive-visible.png)
- [第二案B・FreeCAD](AMR01_SecondDesign_B.FCStd) / [STEP](AMR01_SecondDesign_B.step)
- [上置き比較C・FreeCAD](AMR01_Option_C_TopMotor.FCStd) / [STEP](AMR01_Option_C_TopMotor.step) / [実画面](cad-screen-option-c-top-motor.png)
- [設計要件・三担当の議論・採否理由](DESIGN_REVIEW.ja.md) / [部材の簡易曲げ比較](STRUCTURAL_SCREENING.ja.md)
- [BOM](BOM.csv) / [価格根拠・加工費・送料・差額](cost_summary.json) / [CADから数えた締結部品](fasteners.csv)
- [CAD検証結果と重量内訳](validation_results.json) / [軸・駆動・支持領域の計算](calculation_results.json)

## 同じ要件での比較

| 項目 | 第一案A | 第二案B | 上置き比較C |
|---|---|---|---|
| モーター位置 | フレーム下・同軸 | フレーム下・同軸 | フレーム上・ベルト1:1 |
| 車輪支持 | 二軸受の外側へ32mm張出し | 車輪を内外軸受で挟む | Bと同じ支持配置を仮定 |
| フレームへの取付 | 板＋長さ40mmスペーサ | 内外壁・前後ウェブ・上板、二本のレールと上面/側面へ固定 | 箱支持に加え上軸・調整台 |
| 利点 | 既存案で部品・加工が少ない | 上置き案の伝動部品が不要 | 下部空間・上からの整備性を得る |
| 代償 | 張出しによる軸受反力、スペーサ部の剛性確認 | 新規板材と多数のねじ、芯合わせ、幅拡大 | プーリー・ベルト・別支持上軸・張力調整・ガード |
| 自加工の機械骨格予算 | 34,159円 | **49,763円（+15,604円）** | Bにさらに8,000〜15,000円の未見積枠 |
| 加工外注を含む予算 | 40,159円 | **64,763円（+24,604円）** | 正式見積なし |

価格は購入済み金額ではなく、確認価格・参考価格・未見積枠の合計。電池・電装・ドライバ・センサー・非常停止回路・完成用ガード・荷台・アームは別。自加工は工具を既に持ち、切断・穴あけ・曲げ等を自分で行う条件で、工具購入代と作業費は含まない。外注枠はこれらを加工業者へ依頼する追加予算であり、注文や見積依頼はしていない。

Bの増費の中心は金属素材で、Aの4,100円枠に対して14,842円。Aは素材枠が多く、Bではt4板2枚の販売参考価格を計上しているため、最終見積同士の比較ではない。PLAトレイを使っても、車輪支持の金属板増加を相殺できない。10%予備費は別表示で、自加工54,740円、外注込み71,240円。

## 寸法と選定理由

| 項目 | 第二案B |
|---|---|
| フレーム | NFSL6-3030、400mm×4と300mm×2、外寸460×300mm、床上75〜105mm |
| 純正接合 | HBLFSN6-SET×8。セット付属ナット16＋追加28＝計44個 |
| 機械骨格のCAD外寸 | 460×414×115.6mm。機器・ガード込み目標は500×420×180mm |
| 車輪・軸 | 直径100mm、幅25.4mm、輪距340mm、8×100mm軸 |
| 片側の位置 | 軸受中心y=115/192、車輪中心170mm。右側は鏡像 |
| 駆動 | FIT0185×2、6→8mm継手、車重は別の車輪軸とKFL08で支持 |
| キャスター | Hammer 420G-R50、二駆動輪＋一キャスターを維持 |
| 固定部の最低地上高 | 25mm |
| タイヤ隙間 | 側面金具4.3mm、3030本体7.3mm、上板5mm。公差・変形前の公称値 |
| 重量概算 | 機械骨格6.05kg＋電池・電装等2.05kg枠＝**8.10kg**。10kgまで約1.90kg |

100Nの車輪中央集中荷重を置く同一の梁計算では、第一案の最大軸受反力約219Nに対して第二案は約71N、8mm軸の曲げ応力は約63.7から31.3MPaになる。荷重が軸受の間へ入るためであり、モーター位置を上げた効果ではない。100Nは比較条件で、許容輪荷重や試験荷重を認定した数字ではない。板・角金具・ねじ接合の変形と疲労は別途確認が必要。

車輪支持の改善に対して、輪距は354から340mmへ縮まり、外幅は増える。支持三角形も更新した。電池・アーム等の実重心は未確定で、8.10kgは部品積上げ値、10kgは質量上限である。静的計算にはA相当6.78kg、8kg、B相当8.10kg、上限10kgを使い、各姿勢についてキャスター720方位を比較した。

最大構成14kg、計算条件5度・加速度0.2m/s²・転がり抵抗0.03・余裕1.5では、必要トルクは約0.708N·m/輪。FIT0185の約4.41N·mは拘束値で、連続トルクの裏付けには使わない。初期同時指令の外輪38.39rpmに対し、後期の0.3m/s＋0.6rad/sは76.78rpmとなり、設定する65rpm上限を超える。速度と旋回を組み合わせて制限する必要がある。

## PLAで作る部品

- [機器トレイSTL](EquipmentTrayPLA.stl)：200×180×10.4mm、1個。
- [軸端カバーSTL](ShaftEndCapL.stl)：約20×48×2mm、同じものを2個。

底面をz=0に置いたmm単位のSTLで、両方とも閉じたメッシュを確認した。P1Sの公称256mm角以内。トレイはリブを上にして造形し、軽い電装品用とする。金属スリーブと大径座金で締結部のPLAを直接圧縮し続けない構成。電池や荷物、アームの主固定は金属フレームへ別途設ける。形状・温度・反り・穴公差はスライスと試し刷りで確認する。

## 確認したことと残る条件

369形状が有効で、全67,896組の公称形状検査に体積干渉はなかった。ねじ同士・ナットとの交差も対象に含む。キャスターを5度刻み72方位で回して固定部との衝突がないこと、3輪の接地、地上高、上記隙間、STLの閉鎖性とサイズを確認した。詳細と検査範囲は[検証JSON](validation_results.json)に記録している。

実購入品の形状・公差、工具の進入、角材の内隅R、締結剛性、タイヤ変形、配線はこの検査に含まれない。特に内側上部のM4ナットは対辺をレールに平行に保持する配置で隙間0.5mmとなり、工具厚さを現物で確認する。M4座金はモデルにも数量にも含めていない。緩み止め方法と締付条件は現物部材に合わせて確定する。

純正金具とKFL08は仕様候補を設計へ反映したが、**個人向け購入経路をすべて確定した状態ではない**。フレームは指定のAmazon商品を維持している。KFL08は供給元で穴間隔・寸法・定格が異なり、参考図面と国内販売品の同一性が未確認。ハブ穴・軸嵌合・継手の差込長・モーター連続性能も受入確認対象となる。購入確定用BOMや加工確定図として使わない。

上置きCは軸間90mm、30歯同士、270mmベルトの空間比較。支持台・独立した上軸・ベルト通し窓まで配置したが、部品の確定選定と全締結・全干渉検証は行っていない。Bと同じ検証水準とは扱わない。

## 再生成

通常のPythonで計算する。

```sh
python3 cad/amr02/calculate_design.py
python3 -m unittest discover -s cad/amr02 -p 'test_calculate_design.py' -v
```

FreeCADのPythonコンソールでは、リポジトリの実パスへ読み替えて順に実行する。

```python
for filename in ('build_chassis.py', 'validate_chassis.py', 'capture_screens.py'):
    p = '/home/sadasue/amr-pj/cad/amr02/' + filename
    exec(compile(open(p).read(), p, 'exec'), {'__file__': p})
```

`build_top_motor_comparison.py`は比較Cの別生成コード。各コードは同名の生成ドキュメントを作り直すため、その中の手編集は保存してから実行する。多くの部品位置は生成コード内で定義しており、任意の寸法変更を自動解決する拘束アセンブリではない。変更時は設定・穴位置・BOM・計算を合わせ、再検証する。

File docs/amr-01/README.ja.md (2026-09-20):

# AMR-01 v0.4.1

家庭向けの小型AMRから将来MoMaへ進むための概念設計。Amazonで購入するミスミNFSL6-3030の300mm・400mm材を採用。組立案460×300mm、車輪込み外形500×400mmは配置目標。材料代は各4本入り1組ずつで税込3,419円（確認時点、金具・送料等別）。台車自重の上限は10kg、運搬物2kg（アーム自重とは別）。アーム系は合計2kg以内を仮の拡張枠とする。アームが持ち上げる物体質量は未確定。

**外観を整えるための外装は不要。内部構造と実装を優先し、安全上必要な局所カバーは残す。生成概念画像は不正確なため公開・同梱しない。最新の依頼による実CAD画面はリポジトリへ保存する。**

まず`DESIGN.ja.md`を読む。このZIPは設計書と計算のみ。第一案CAD、部品表、実CAD画面は[GitHubのcad/amr01](https://github.com/sige0002/amr-pj/tree/main/cad/amr01)に別置。実機制御コードは含まない。

機械骨格の支出目安は自加工34,159円／外注加工枠込み40,159円。電装等は別。骨格約4.73kg＋電装等予算2.05kg＝約6.78kgで、上限10kgまで約3.22kgの余裕がある。FIT0185の連続定格は未確認で、低速試験用の第一案とする。

## 再計算

Python 3.10以降。追加パッケージは不要。

```bash
cd amr_v0_4_1
python3 check_design.py
python3 -m unittest -v test_check_design.py
```

`check_design.py`は同じフォルダーの`design_parameters.json`を読み、同じフォルダーの`calculation_results.json`を更新する。任意の作業ディレクトリからも実行できる。

```bash
python3 check_design.py --config design_parameters.json --output results_trial.json
```

入力の寸法はキーの`_mm`、内部の重心計算はmで扱う。荷物の上限とアーム系の重量は別管理する。`arm_object_lifting_limit_kg: null`は未確定を示し、0kgという意味ではない。

定尺・本数から組立外寸と購入数量を照合し、予備材込みの購入費と実使用材の機体質量を分けて出力する。3030と4040の梁単体の比較も含む。

静的計算の`operation_approved`は常に`false`。支持余裕が正でも、強度・制動・全姿勢・動力学を検証したことにはならない。`static_moment_ratio: null`はその計算姿勢で転倒側モーメントがゼロであることを示し、安全認定ではない。

テストは計算と入力制約の確認のみ。物理機体の安全性、部品の入手性、家庭での運用可否は保証しない。変更後は設計書・変更履歴も更新する。

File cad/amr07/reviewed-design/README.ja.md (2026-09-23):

# E4：レビュー反映後の標準設計

**機構設計とロボット・電装の2つの独立AIレビューを受領してから修正した。** 人間専門家の認証や実機試験ではない。3030骨格・二階構造・電池の後方交換は維持し、天板の使いやすさとスイッチの組立・整備を改善した。モニターは[別のオプション](../monitor-option/README.ja.md)であり、標準CAD・重量・BOMに含めない。

[標準BOM](BOM.ja.md) ／ [全明細Markdown](BOM-details.ja.md) ／ [CSV](BOM.csv) ／ [配線・復帰仕様](WIRING.ja.md) ／ [レビューと対応表](../design-review-e3/README.ja.md)

FreeCAD実画面：E4標準

## 天板の変更

| 項目 | E4 |
|---|---|
| 板 | 6061-T6、300×300×4mm、上面233mm |
| 拡張穴 | φ4.5通し穴25個。X/Yとも−100、−50、0、50、100mm。原点あり、50mmピッチ |
| フレーム固定 | X=−125、0、125mm×Y=±135mm、計6点。φ6.6通し穴 |
| 固定ボルト | NBK SSH-M6-12、頭径10・頭高さ1.5mm・六角3mm。従来の頭高さ6mmから低頭化 |
| 荷面 | 常設の15mm高ストッパ4個を標準から撤去。中央250×250mmの箱を置く例をCAD確認 |
| ベルト長穴 | 30×6mm、端R3を4個。X±140/Y0に長手Y、X0/Y±110に長手Xで対称配置 |
| 取外し | 荷物とベルトを外し、上から6本を外して天板を持ち上げる。ヒンジなし |

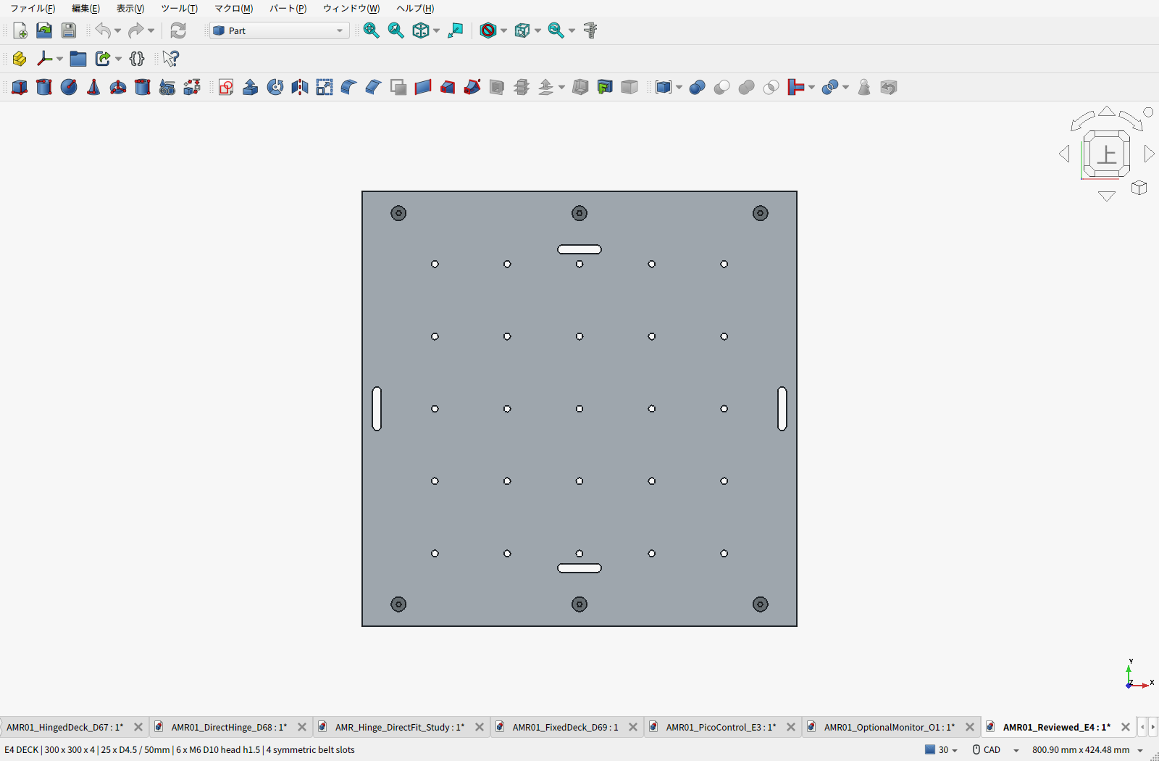
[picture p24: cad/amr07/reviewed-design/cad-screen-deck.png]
FreeCAD実画面：中心格子と外周の固定点


穴数を36から25へ減らしたのは、旧配置の12穴にあったフレーム付近の裏側工具制約を避け、全穴で同じ貫通締結を使えるようにするため。25mmピッチ81穴案も比較したが、追加加工と費用未確定を避けるため標準には採らず、小物はPLA変換板で対応する。極低頭を使い、板の皿加工は追加しない。天板全体が完全な平面になるわけではなく、外周には1.5mmの頭が残る。

電池を外した状態で全25穴の下面φ12×40mm工具空間を確認。**電池装着時はX=−100/Y=−50,0,50の3穴の下面工具がアダプターに当たる。** これらは電池を外して作業する。固定ボルトの工具空間と、250角の荷物例は標準状態で干渉なし。実際の取付ねじ長さは機器ごとに決め、1階機器へ長いねじを突き出させない。

[メーカーSSH寸法](https://www.nbk1560.com/products/specialscrew/nedzicom/socketheadcapscrew/SSH/)に基づく。メーカーの6.3N·mは参考上限で、推奨作業値ではない。通常M6の締付値をそのまま使わない。[天板の追加強度レビュー](../design-review-e3/DECK_REVISION_CHECK.ja.md)では通常10kg・静的15kg×荷重係数2の簡易比較を実施。板全体の曲げには余裕があるが、長穴周り・ベルト張力・接触・締結・実物の強度確認は残る。

## スイッチの変更

**公開寸法の照合追補**：[寸法根拠と修正点](SWITCH-DIMENSIONS.ja.md)。3214の仮円柱をメーカー外形19.5×30.5mm・前方高さ21.5mmの包絡形状へ修正。HWの接点/レバー包絡と回り止め切欠き寸法も訂正した。

二つの箱は中央の電池交換口を挟んで維持する。非常停止はHW1B-V402Rの2NCで左右モーター電源を別接点で遮断する案、主電源は計算機を含む全負荷用のamon3214。箱の高さを決める接点・端子があるため、外観だけで箱を縮小しない。

- 非常停止：メーカー掲載のφ28.4×5mmロックナットを別部品としてCADへ追加。φ29の工具確認空間を設け、蓋裏リブへ当たらないことを確認した。
- 主電源：中心は従来のX=−201/Y=64mmを維持。ナット周辺にφ31のリブ逃げとφ34の補強環を設けた。φ26×5mmナットとφ30工具は**設計上確保する仮寸法**で、実測ではない。
- 250型端子とHW配線の確保空間を色分けした。主電源の接続メス端子/完成リードは型番未選定。HW端子中心座標は参照カタログに寸法記載がない。確保空間を実部品の確定形状として扱わない。
- 両箱に配線の結束橋を追加。蓋・箱・床は各4本のM4による既存固定を維持する。

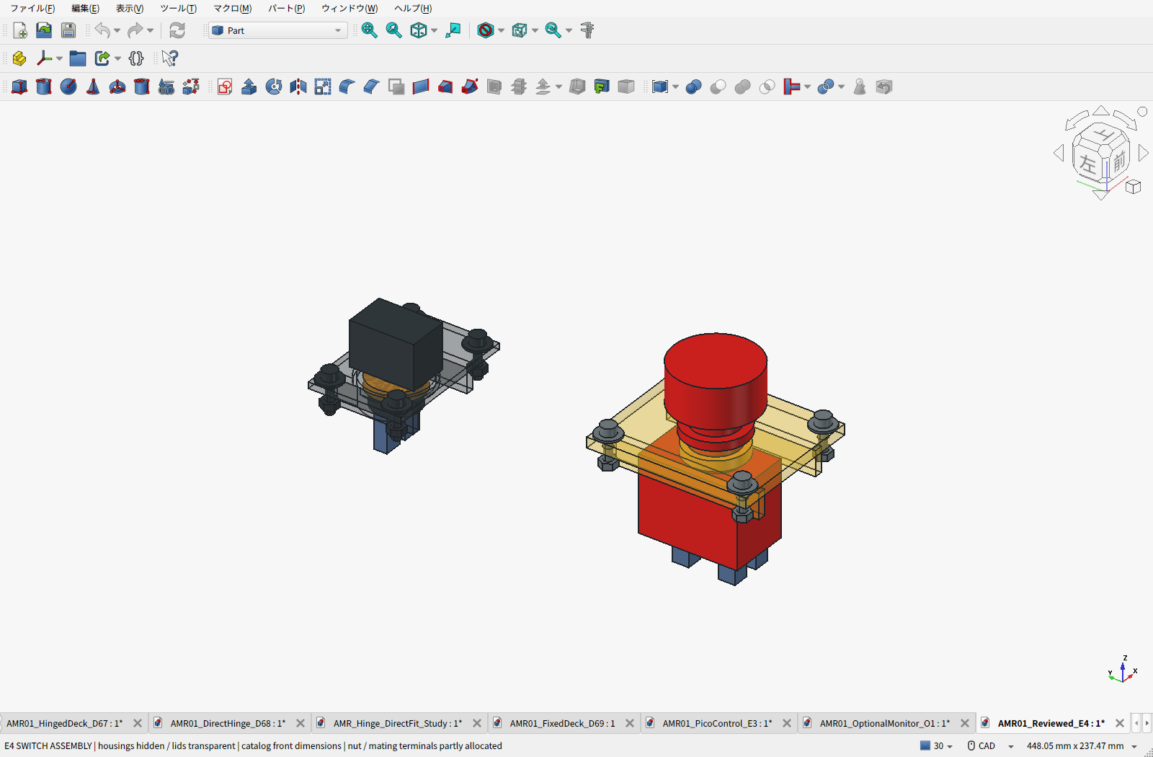
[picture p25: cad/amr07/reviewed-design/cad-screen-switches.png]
FreeCAD実画面：箱を非表示、蓋を透過した取付部


組立は電池を外し、蓋を机上に置いて「スイッチ挿入→ナット締付→HW接点ブロック/付属レバーストッパ装着→端末加工済み線の接続→線保持→蓋を閉じる」の順。主電源の樹脂ナットも蓋裏から締める。表示は黄色面の赤ボタン付近にMOTOR STOP、黒い箱のスイッチ脇にMAIN POWERとし、実品ON/OFF方向を確認して付ける。

ナットの持続締付を受けるPLAは、押下150Nの梁計算とは別にクリープ・回転解除・繰返し押下を実機確認する。指定締付を勝手に下げて合格扱いにしない。主電源ナットの未掲載寸法、未選定の接続端子、非常停止の実負荷・突入適合は別々の未解消事項として残す。公開済みの外形まで現物待ちとはしない。

## 確認結果と費用

車体推計**10.363kg**（E3比約93g減、実測前）。通常積載10kg・静的比較15kg/SF2の条件を維持する。標準PLAは12部品。

変更部9,018組で新規干渉なし。天板・電池取り外し、上方/後方の非常停止操作、主電源操作、ナット工具、蓋50mm取外しを確認した。蓋は5mm刻み、ハーネス移動は2mm刻みの検査であり、実配線の連続変形や曲げを検証したものではない。スイッチ蓋の整備は電池を外す条件。

**新天板は未見積。** 旧D3の28.67USD＋送料9.98USDは穴配置が違うため流用しない。現在の計上済み小計は約88,560円＋新天板・送料・PC・給電・HAT・最終配線等の未計上分。旧小計との差を節約額と説明しない。低頭ボルトはメーカー参考528円/10本、個人購入先・送料・Prime適用は未確定。

- [標準FreeCAD](AMR01_Reviewed_E4.FCStd) ／ [STEP](AMR01_Reviewed_E4.step)
- [新天板加工用STEP](E4_Deck_300x300x4.step) ／ [穴配置図](deck-layout.svg)
- [PLA試作12部品ZIP](E4-print-prototypes.zip) ／ [干渉検査](validation.json) ／ [保存物照合](saved_artifact_validation.json)
- [設計要件](requirements.json) ／ [寸法・重量](geometry.json) ／ [元E3](../pico-control/README.ja.md)

ファームウェアは仕様のみで未実装。停止後の古い指令破棄、片輪異常時の両輪禁止、ゼロでの再接続と明示RUNを仕様へ追加した。短時間電源断の検出保証・接点突入適合・完成ハーネス・Pico実装状態は、CAD修正だけで完了にできない。

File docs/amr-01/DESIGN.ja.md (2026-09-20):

# AMR-01 設計案 v0.4.1 — 台車自重上限10kgへの改訂

更新日：2026-09-20  
更新元：AMR-01 v0.4.0（第一案の形状を維持し、ユーザー指定の台車自重上限10kgを反映）
**段階：フレーム断面・購入定尺・平面外寸を決定。車体全体は概念設計で、製作図・完成部品表・実機性能保証ではない。**

本版は第一案Aの基礎設計基準を保存する。第二案Bと上置き比較Cは[リポジトリの第二案資料](https://github.com/sige0002/amr-pj/blob/main/cad/amr02/README.ja.md)を参照。**外観を整えるための外装は不要。内部構造・荷重経路・駆動系・電装配置・整備性を優先する。生成した概念画像は不正確なため、設計書にも配布ZIPにも収録せず、設計根拠に使用しない。**

旧版の大型アーム・40kg級台車を前提にした寸法、駆動仕様、把持条件は適用しない。数値を小さく置き換えるだけでなく、重量予算・支持領域・運転範囲・未決定事項を定義し直した。

第一案の[実CAD・BOM・費用内訳](https://github.com/sige0002/amr-pj/tree/main/cad/amr01)を追加した。ユーザーの最新指示に従い、FreeCADの実画面はリポジトリへ保存する。生成概念画像の除外方針は維持する。

**骨格の支出目安は自加工34,159円、外注加工枠込み40,159円。電装・ガード・アームは別。重量は骨格約4.73kg、電装等の予算込み約6.78kg。台車自重上限10kgに対して約3.22kgの余裕がある。** 価格確認済みと見積枠、形状確認済みと実測待ちをCAD資料に明記した。

## 1. 目的と確定条件

目標は将来のMoMa（移動マニピュレータ）化。その入口として、家庭内で使う小型AMRを製作する。

**現行条件は「カチャカ以上のサイズ感」「Amazonで買えるサイズに限定してフレームを決める」「2020の強度に不安がある」「300mm・400mm材を使い、3030か4040かを費用も含めて判断する」。これを受け、ユーザー提示のAmazon販売品・ミスミNFSL6-3030を採用する。運搬物2kg・アーム自重は別枠という要求は維持する。** 家の通路幅・収納寸法・床条件はまだ実測していないため、家庭内への適合が確認できたとは扱わない。

| 区分 | 現行条件 | 状態 |
|---|---|---|
| 運搬物 | 合計2kg以下。荷台の物体と把持中の物体を合算 | ユーザー要求。合算方法は設計上の定義 |
| アームとの区別 | アーム系の自重は運搬物2kgに含めない | ユーザー要求 |
| サイズ・調達 | カチャカ以上のサイズ感、Amazonで個人購入できる定尺フレームを使用 | ユーザー要求 |
| 主フレーム | MISUMI NFSL6-3030、平面外寸460×300mm、切断なし | 本版で決定 |
| 外装・外観 | **外観を整えるための外装は不要。内部構造を優先** | ユーザー要求 |
| 概念画像の扱い | **生成画像は公開・同梱しない。画像中の形状・配置を仕様とみなさない** | ユーザー要求 |
| 外形 | 長さ500×幅400mm、車輪・ガード・収納した持ち手込み | 本版の設計目標 |
| 台車高さ | 160〜180mm、アーム・センサーポールを除く | 本版の設計目標 |
| 台車自重 | 10kg以内。搭載電池・計算機・センサー・保護回路を含む | 最新ユーザー要求。現案約6.78kgは概算 |
| 将来のアーム系 | アーム、グリッパー、専用取付板、専用電装・電源等を合計2kg以内 | 仮の拡張予算。採用機種なし |
| 最大構成の総質量 | 台車上限10kg＋アーム系2kg＋運搬物2kg＝14kg | 上記から計算 |
| アームが持ち上げる物体 | **未確定** | 運搬2kgを、そのまま把持能力と解釈しない |

アーム系に別バッテリーや制御箱を追加する場合も、その質量を上記のどちらかへ必ず計上する。荷物と別だからといって、アーム用機器を無制限に追加しない。

寸法・質量に収まらないときは、まず部品・配置・構造・搭載機能を見直す。可搬2kgや停止・保護機能を無断で削らず、車体拡大・重量上限引上げにも自動的に戻さない。

### 1.1 初期運用の範囲

屋内の乾燥した水平な硬い床、監督者のいる隔離された試験区画から開始する。初期速度は0.15m/s以下、初期旋回角速度は0.3rad/s以下。検証後の目標上限は0.3m/s・0.6rad/s、並進加速度は0.2m/s²以下とする。

坂5°は駆動力の計算条件であり、走行許可ではない。段差の高さ・形状、ラグ、敷居、コード、床への傷、キャスターの向き直しは実物で確認する。階段、濡れ床、屋外、無監督で人やペットと共有する運用は初期範囲外。

アームは移動時に収納し、水平床で停止・保持成立を確認してから正面を操作する。初期は移動とアーム動作を同時に行わない。

### 1.2 外装不要・内部構造優先の方針

初号機はフレーム、駆動系、電池、電装の構成が確認できる実用的な試作機とする。意匠用の外殻、化粧板、装飾部品、外観目的の塗装・曲面加工は要求に含めない。見栄えを整えるために質量、寸法、費用、整備の手間を増やさない。

「外装不要」は「保護不要」ではない。車輪・ベルト等の巻き込み防止、端子の接触・短絡防止、鋭利部の保護、電池・配線の固定に必要な局所カバーやガードは設ける。構造板・アーム取付板も必要な機械部品として残す。これらの質量と外形は既存の予算へ計上し、装飾用外装の枠は新設しない。

内部設計は、荷重経路、車輪支持と動力伝達、停止・保持、電源保護、配線の分離、電池脱着、工具アクセスの順に具体化する。前に生成した概念画像は各部の寸法・位置・支持方法が未検証であるため採用しない。今後の製作図は、本文の数値と実部品CADを根拠に作成する。

## 2. 機械構成と配置

### 2.1 決定したフレーム寸法と配置の暫定値

車体中心の床面を原点、xを前、yを左、zを上とする。以下の単位はmm。主フレームの断面・平面外寸・定尺長を決定し、車輪・キャスター・電装の位置は配置案とする。購入材は切断せず、取付板の穴位置は実部品のCAD配置後に決める。

| 部位 | 現行配置・寸法（v0.4.0） |
|---|---|
| 車体外形 | 500×400、高さ160〜180 |
| 主フレームの平面外寸 | 460×300 |
| 主構造材 | 30×30、低い外周フレーム＋内部の長手補強材2本・必要な構造板 |
| 駆動輪 | 直径100、幅25.4、左右2輪。Amazon B0B23WBLBKを第一案に選定 |
| 左右駆動輪接地点 | (90, +177)、(90, -177) |
| 車輪中心間隔 | 354。軸カラーとハブ取付ねじの隙間を確保 |
| 後方キャスター | ハンマー420G-R50、直径50、旋回軸(-150, 0) |
| キャスターのトレール | 16（420G-R50） |
| キャスター金具込み旋回半径 | 45以下を目安、採用品で確認 |
| 最低地上高 | 25を目標、キャスター・モーター金具を含めて確認 |
| アーム取付中心 | (60, 0, 170)を仮置き |
| アーム用プレート | 前後140×左右180×厚さ4の初期案。アーム系の重量へ計上 |
| 電池 | 低い位置で固定、機体を大きく分解せず取り外せる配置 |
| 持ち手 | 収納時は外形内、台車を持ち上げるための構造部へ接続 |

計算上、車輪外端はy=±189.7、内端はy=±164.3。フレーム側面から車輪内端まで14.3mm、車輪外端から幅400の境界まで10.3mm。軸端はy=±197で境界まで3mmのため、軸端ガードの取付余地は別途再検討する。キャスター包絡の後端はx=-195で長さ500の内側に入る。ただし、これは単純な外形計算だけであり、ハブ、配線、ベルト、モーター、ねじ、カバー、タイヤ変形まで収まることの確認ではない。

### 2.2 2輪差動駆動＋後方1キャスター

前寄りの左右輪を独立駆動し、後方中央の1キャスターで支持する。初期はサスペンションを設けない案とする。

**支持領域は長方形の車体外形ではなく、接地点による三角形。** 後方・側方にアームを伸ばしてよいとは扱わない。キャスターの向きで接地点が変わるため、静的計算ではトレール16mmを全周1440方向でサンプリングする。有限サンプリングであり、連続全方位の厳密保証ではない。

前面中央にはアームが床へ向かう経路を確保する。車輪・伝達部・鋭い端部を覆い、電池・荷物が動かないよう固定する。アームの実軌道が決まるまでは、カメラ等の前面突出位置を確定しない。

### 2.3 旋回スペース

車体が左右対称でも、旋回中心は車体中央ではなく、x=90の車軸中央になる。

その場旋回時に車体矩形が通る範囲の直径は、

```text
D = 2 × sqrt((500/2 + 90)^2 + (400/2)^2)
  = 788.9 mm
```

**保管時は500×400mm、理想的なその場旋回では車体だけで直径約789mm。** 壁との余裕、制御誤差、物体、収納アームのはみ出しは別に加える。幅400mmの隙間で旋回できるという意味ではない。

最小通路幅、曲がり角、収納高さ、運搬経路、電池を抜く方向は実測して照合する。室内寸法の確認前に「家に入る」と確定しない。

### 2.4 内部構造・機器配置の設計方針

以下は内部設計で確保する機能と配置方針であり、生成画像の部品形状や寸法を採用するものではない。フレームの購入品と公称寸法は4.1節で決定した。駆動系・キャスターの第一案は末尾のCAD節と部品表で選定した。電池等は未選定。

| 区画・部品 | 配置・支持の方針 | 詳細設計で確認すること |
|---|---|---|
| 下部主フレーム・底部 | 30mm角の低い外周フレームと内部の長手補強材を基本に、必要な構造板・ガセットで補強 | 荷重経路、接合部、最低地上高25mm、締結工具の進入 |
| 左右の駆動系 | x=+90mmの車軸位置と車輪間隔354mmを基準に左右独立配置 | 車輪荷重を受ける軸受、減速機定格、伝達部、保持機構、平面外寸460×300mmのフレームとの干渉 |
| 後部の支持系 | キャスター旋回軸を(-150,0)mm、直径50mmで仮配置 | 旋回半径45mm以下を目安に、金具・配線・床との干渉を確認 |
| 電池 | できるだけ低い位置に機械的に固定。計算上の重心に近づける配置を検討 | 採用パックの実寸・質量、着脱方向、抜き差しの空間、端子保護、主ヒューズへのアクセス |
| 制御基板・電源分配 | 取り外し可能な小型取付板を使用し、駆動部・電池脱着経路から分離。必要なら上側の空間を使う | 基板固定、電気絶縁、放熱、コネクター抜き差し、冷却部を含む質量 |
| 将来のアーム取付部 | (60,0,170)mmを基準に、専用取付板をアーム専用台座・内部の長手補強材2本で支える | 140×180×4mmの仮プレートの強度、取付穴、干渉、配線経路。画像中の大型天板は採用しない |
| 配線 | フレーム沿いに固定し、動力配線と信号配線を整理する | 車輪・キャスター・可動部との離隔、曲げ半径、張力止め、保守用の余長 |
| 非常停止・保護 | 機体から直接操作でき、積載物や将来アームで隠れない位置 | ハードウェア停止経路、操作性、惰行・保持挙動、再始動防止 |

上側へ基板を置く場合も、重い電池や駆動部は低位置を優先し、搭載後の重心を実測する。画像に描かれた上下二段の箱型フレーム、モーター直結構造、基板サイズ、電池形状などは確定仕様として引き継がない。内部が見えることと、運転中に危険な回転部や電極へ触れられることは分け、必要な部分だけ保護する。

## 3. 重量予算

ユーザーの指示により、台車自重は電池・電装を含めて**10kg以内**とする。6kgの達成目標は撤回する。現案見込みと上限を分け、軽量化だけを目的とした高価な部品変更を優先しない。

| 区分 | 現案の質量見込み・予算 |
|---|---:|
| 機械骨格（フレーム、支持板、締結材、モーター、車輪、軸受、キャスター） | 約4.73kg |
| 電池・取付アダプター | 0.75kg |
| 電源変換・保護・非常停止 | 0.40kg |
| 搭載計算機・センサー・冷却 | 0.50kg |
| 配線・機能ガード・持ち手 | 0.40kg |
| **現案合計** | **約6.78kg** |
| **台車自重上限** | **10.00kg** |
| **上限までの残り** | **約3.22kg** |

骨格4.73kgは公称質量とCAD体積からの概算で、電装等2.05kgは未選定部品の予算。実測重量ではない。未選定の保持機構、補強、電池・計算機の仕様変更は残り約3.22kgの中で管理する。現案の最大構成見込みは6.78＋2＋2＝10.78kg、駆動力の設計計算には上限構成14kgを用いる。使用押出材は2.20m・1.672kgで変更しない。

アーム専用プレート・台座はアーム系2kg枠に計上し、実アーム選定後に決める。ラジコン段階で上位計算機等を未搭載とする場合も、将来追加時には再計量する。特定の計算機やLiDARが0.50kg枠内に入るかは未確認。
アーム系2kgの予算は別管理し、取付板や専用電源も含める。大型アームに備えたバラストは標準装備しない。軽く完成した場合は、その実質量で安定性を再計算し、予算上限まで載っていると仮定しない。

## 4. フレーム・車輪支持

### 4.1 Amazonの300mm・400mm材、3030を採用

採用材は**ミスミ NFSL6-3030、6シリーズの軽量タイプ、30×30mm**。ユーザー提示のAmazon商品は300mm品NFSL6-3030-300で、同シリーズの400mm品も確認した。材質A6063S-T5、白アルマイト、質量0.76kg/m、断面二次モーメント2.68×10⁴mm⁴。[S1][S7] 太さの検討には「3030」という外寸だけでなく、この商品の断面定数を使う。

| 用途 | 購入定尺 | 使用本数 | 購入単位 | 確認した税込価格 | Amazon商品 |
|---|---:|---:|---|---:|---|
| 左右外周＋内部の長手補強材 | 400mm | 4本 | 4本入り1組 | 1,952円 | [NFSL6-3030-400](https://www.amazon.co.jp/dp/B0DKF2CCW3) |
| 前後の横桟 | 300mm | 2本 | 4本入り1組、2本予備 | 1,467円 | [NFSL6-3030-300](https://www.amazon.co.jp/dp/B0DKDZ8G9G) |
| **購入小計** | | **6本使用** | **計8本購入** | **3,419円** | 金具・板材・送料は別 |

2026-09-20に各商品の選択ASIN・寸法・断面定数・4本入り表示・税込価格・注文ボタン・販売元ミスミを確認した。購入操作は行っていない。販売者には「3,000円以上で送料無料」の表示があるが、配送先と適用条件を含む最終送料は注文画面で確認する。

300mmの前後材を幅方向に通し、その間に400mmの長手材を入れる組立案とする。**外寸は長さ30＋400＋30＝460mm、幅300mm**。内部の長手補強材2本も400mm材を使う。外周内側は前後400×左右240mmで、補強材の間隔は搭載品に合わせて決める。300mm・400mmは購入材の長さであり、組立後の外寸とは区別する。車輪・ガード込み500×400mmは配置目標で、実部品CADによる適合確認はこれから行う。

使用材は合計2.20m・1.672kg。購入材は合計2.80m・2.128kgだが、予備の300mm材2本は機体へ載せない。**切断・長さ特注・端面タップを前提にしない。** アーム取付高さ170mmは暫定値で、専用台座は実アームと干渉を確認して設計する。未選定の100mm支柱等を購入一覧へ追加しない。

締結金具はミスミ6シリーズ・30角に適合するブラケットとM6溝ナットを選定する。外寸30角だけを根拠に他シリーズの金具を共用しない。外周の直角保持と車輪支持部はガセット等で補強し、アーム取付部は取付板・専用台座から内部補強材と外周へ荷重を分散する。金具の型番・個数、板厚、締結トルクは詳細設計で確定する。

### 4.2 太さの判断：3030を採用し、4040へ全面変更しない

**300〜400mmの3030定尺を維持し、費用を考慮して必要箇所を補強する方針とする。下記100Nの梁比較は固定条件の参考例であり、上限構成14kgの完成車体を検証した結果ではない。** 接合部の滑り・緩み、車輪の局所荷重、アーム取付部の変形は別に確認し、必要な箇所を補強する。

比較条件は、支間400mmの両端単純支持梁1本の中央に100N（約10.2kgf）を集中載荷、ヤング率69,000N/mm²を仮定する。これは実機の全荷重経路を再現した計算でも、完成台車の定格試験でもない。

| 項目 | 採用3030：NFSL6-3030 | 比較用4040：HFSL8-4040 |
|---|---:|---:|
| 断面二次モーメント | 26,800mm⁴ | 75,400mm⁴ |
| 単位質量 | 0.76kg/m | 1.27kg/m |
| 上記条件での計算たわみ | 約0.072mm | 約0.026mm |
| 同じ使用材長2.20mでの質量 | 1.672kg | 2.794kg |

3030の入力はAmazon商品仕様とメーカー強度目安表、4040はメーカーの軽量タイプ仕様を参照した。[S1][S7][S8] 4040の曲げ剛性は同じEの仮定で約2.81倍になる一方、同じ使用材長でも約1.12kg増える。4040の材質はA6005CSS-T5で、NFSLのA6063S-T5とは異なるため、耐力や破断荷重が同じ比率になるとは扱わない。4040は比較用であり購入対象ではない。

```text
delta = P × L^3 / (48 × E × I)
      = 100 × 400^3 / (48 × 69000 × 26800)
      = 0.0721 mm
Z = I / (30/2) = 1786.7 mm^3
sigma = (P × L / 4) / Z = 5.60 MPa
```

荷重を仮に3倍の300Nとした感度計算でも、梁単体ではたわみ約0.216mm、曲げ応力約16.8MPaとなる。ただし、3倍が実機に必要な衝撃係数を満たすという意味ではない。片持ち支持、ブラケットの回転・滑り、溝の局所変形、板のたわみ、車体のねじれ、アームの曲げモーメントはこの計算に含まれない。

4mm厚のアーム専用プレートは初期案のまま、実アームの荷重・ボルト配置から検証する。3030と適切な接合補強で許容変形を満たせない場合、または支間・アームモーメントを増やす場合に4040を再検討する。運搬物の要求は2kgを維持し、5〜10kgを可搬定格として採用しない。

### 4.3 費用の管理

初回の押出材購入は上表の2組、税込3,419円を基準とする。予備材も購入費には含め、機体質量からは除く。価格は確認時点の表示であり固定見積ではない。フレーム材だけの金額を「骨組み一式」や「台車総額」として提示しない。

ブラケット・溝ナット・ボルト・ガセット・取付板まで含む第一案の費用を12節とCADフォルダーのBOMへ計上した。金具との適合、必要個数、送料まで含む総額を比較する。使わない支柱や全面4040化を先に追加せず、必要な接合部・車輪支持・アーム取付部の補強へ費用を配分する。4040のAmazon実売価格は今回未取得のため、価格差の数値は置かない。

### 4.4 軽量な駆動ユニットを選定する条件

車輪軸の荷重をモーター減速機が受ける場合は、ラジアル荷重・アキシャル荷重・許容片持ち長さを確認する。第一案では独立軸受で車輪を支持し、カップリングで同軸に伝達する。旧版の大型の独立軸・ブレーキ・伝達部をそのまま流用しない。

車輪・キャスターの支持荷重を総質量/3で選定しない。各積載・アーム姿勢の接地反力、偏荷重、床の継ぎ目、制動時荷重を求めて定格と照合する。第一案は径50mm・許容荷重300Nの420G-R50を選定したが、家庭の敷居・ラグで適すると保証しない。

## 5. 駆動系の再計算

| 計算入力 | 値 |
|---|---:|
| 最大構成の総質量 | 14kg |
| 車輪半径 | 0.05m |
| 並進加速度 | 0.2m/s² |
| 勾配 | 5°、計算用 |
| 転がり抵抗係数 | 0.03、仮定 |
| 車輪数 | 左右の駆動輪2輪 |
| トルク余裕係数 | 1.5 |

```text
F = m a + m g sin(theta) + Crr m g cos(theta)
  = 18.874 N
T = F r / 2 = 0.472 N·m / 輪
T × 1.5 = 0.708 N·m / 輪
```

従来の部品探索目標は**車輪軸で連続0.8〜1N·m程度、最低使用電圧で負荷回転数約80rpm**。第一案は費用を優先してFIT0185を選定したが、この連続動作点を確認できていない。初期低速試験用とし、最高速度・旋回は各輪65rpmの暫定指令上限で結合制限する。カタログの最大値・拘束トルクを連続値として使わない。24V表記のモーターを18V系で使うなら、その動作点の回転数・トルク・発熱を確認する。伝達損失は車輪より上流の選定時に加算する。

0.3m/s直進には57.3rpm、0.3m/sと0.6rad/s旋回を同時に要求すると、車輪間隔354mmの場合の外輪は77.6rpmとなる。このため80rpmを探索目安にする。ただし、坂での直進トルクと旋回回転数を別々に計算しただけで、坂での旋回抵抗まで検証したものではない。

ピークトルク、ピーク電流、許容時間は未確定。電流制限とタイヤ摩擦も設計する。トルクが大きければ安全とは扱わず、必要以上の押し付け力を生じない設定にする。

## 6. 将来のアームと転倒条件

### 6.1 運搬と把持を分離する

**2kgを荷台に載せて運ぶことを目標とし、2kgをアームで持ち上げるとは定義しない。** 500g等の把持重量もまだ採用条件ではない。旧版の「床から物体2kgを把持」「600mm級・自重10kgアーム」は本版では適用しない。

アームの採用条件は、系全体2kg以内、収納時の平面外形が原則500×400mm以内、必要な手先姿勢、床と車体との干渉回避、取付部強度、停止中の保持、全軌道の転倒余裕が成立すること。これらが成立する機種を未選定である。

参考として、肩を(60,0,240)、手先を(280,0,30)と置くと直線距離は304.1mm。リーチの公称値がこの距離を超えるだけで到達できるとは扱わず、逆運動学、肘の逃げ、グリッパー姿勢、特異姿勢を確認する。

### 6.2 車輪配置変更後の静的感度計算

現案の質量見込み6.78kgと上限10kgを比較する。従来5/6kgは軽量時の感度例として計算JSONに残す。**台車重心(0,0,85)mmは全ケースで仮定値。10kg時の復元力を6.78kgの現案へ適用しない。** 荷台の物体は把持姿勢のカウンターウェイトに含めない。

| 構成物 | 質量 | 重心x | 重心z |
|---|---:|---:|---:|
| 台車 | 6.78kg / 10kg | 0mm | 85mm（仮定） |
| アーム・取付・専用機器を仮集約 | 1.7kg | +160mm | 240mm |
| グリッパー | 0.3kg | +280mm | 40mm |
| 把持物の感度計算 | 0 / 0.5 / 2kg | +280mm | 40mm |

前方転倒支点は駆動輪接地点を結ぶx=90mmの線。

| 台車質量 | 仮の把持物 | 復元/転倒モーメント比 | 前方支持辺までの重心距離 |
|---|---:|---:|---:|
| 6.78kg | なし | 3.467 | +49.5mm |
| 6.78kg | 0.5kg | 2.252 | +36.6mm |
| 6.78kg | 2kg | 1.097 | **+5.0mm** |
| 10kg | 0.5kg | 3.321 | +50.3mm |
| 10kg | 2kg | 1.619 | +24.6mm |

現案見込みの2kg把持例は静的には支持辺の内側だが、余裕5mmだけで動的安定性や把持能力が成立したとはいえない。軽量感度例5/6kgでは以前と同様に前方転倒側になる。実アームの質量分布、配置、物体との距離で結果が変わる。

アーム収納2kg・荷台2kgの仮配置では、キャスター全周サンプリングの最小静的支持余裕は台車6.78kgで約82.6mm、10kgで約81.8mm。荷物の移動、横張り出し、高い重心、傾斜、加減速、停止、接地の弾性は未検証。
必要な静的余裕の数値、動的許容範囲、把持重量は、実部品・使用場面・誤差を含めて別途決める。**本計算は運転許可判定を出さず、全ケースを未承認として出力する。**

不足時は、まずアームの軽量化、取付位置、リーチ、作業範囲を見直す。車体拡大やバラスト追加で解決することを既定路線にしない。

## 7. 電源・停止・保持

### 7.1 電源モジュール

マキタ18V電池の流用方針は残すが、採用品・容量・重量は未確定。MakitaのSTAR Protectionは工具と電池間で情報を交換する方式と説明されており、単純な2端子アダプターだけで同等の保護が成立するとは扱わない。[S2]

機外で正規充電器を使用し、パックを加工しない。主ヒューズ、過電流、過放電、温度異常、個別セル保護、配線・コネクター定格の成立を確認する。総電圧監視だけで個別セル保護を代用したと判断しない。これらを確認できない構成で走行試験を開始しない。

電池→主ヒューズ→分岐を基本構成とし、走行系と計算機・制御系を分ける。走行系には停止経路、駆動段、必要な回生エネルギー対策を設ける。実際の回生有無・母線電圧上昇を採用ドライバーの仕様で確認する。回生型ドライバーのメーカー仕様を参照資料として残すが、旧版のSabertooth 2x32を採用決定したものではない。[S3]

満充電、電池側遮断、主電源開放、電源装置での試験時も確認する。保護回路・回生吸収の電圧や電流定数は部品選定後に決める。

将来アームに別電源が必要なら、重量と外形に含めて再配分する。18V電池でアームまで必ず動くとは定義しない。

### 7.2 停止と位置保持

機体上にラッチ式非常停止を設け、PC・ROSを経由しないハードウェア経路を持たせる。解除しても自動再始動させず、明示的な運転再許可を必要とする。

**駆動禁止は停止完了と同じではない。** 駆動を切ったときに惰行する、保持が失われる等の挙動を調べ、制動と保持を合わせて設計する。PCの停止指令、PWMゼロ、減速機の摩擦だけで停止・保持を保証しない。

保持方式は軽量なブレーキ等を含めて未選定。保持専用品を走行中の非常制動に使う場合は対応定格が必要。方式未確定のまま坂道やアーム操作を解禁しない。アームは電源喪失時の重力落下・物体落下も別途考慮する。

遅延0.2s、減速度0.5m/s²を仮定した理想化された制御停止距離は、初期0.15m/sで52.5mm、上限0.3m/sで150mm。これは非常停止の性能保証ではなく、実際の停止距離は床・積載・制動方式別に測定する。

### 7.3 稼働時間は未確定

計算例として18V・6Ah、使用可能率80%、平均消費30Wなら2.88時間、50Wなら1.73時間。第一案のモーターは12Vなので18Vを直結する仕様ではない。電池も電力も仮定であり、採用電池の重量予算適合、実測稼働時間、アーム込みの稼働時間を意味しない。容量を増やす前に台車質量・収納寸法と照合する。

## 8. 制御と段階的拡張

初期構成はラジコン受信器→マイコン→左右ドライバー。エンコーダで車輪速度を閉ループ制御し、受信途絶、PC通信途絶、マイコン異常、電圧異常を検出する。ラジコンとPCの指令を同時に採用しない。

USBを初期接続候補、CANを拡張候補とする。エンコーダ、車輪速度、電流、電圧、許可状態、故障を記録できる構成にする。制御周期・通信タイムアウトは機器の能力と停止距離から定め、ROSの既定値を安全性の根拠としてそのまま採用しない。

ROS化では`ros2_control`の`diff_drive_controller`を候補とする。車体速度指令から車輪指令を生成し、実測フィードバックによるオドメトリ、速度・加速度等の制限、指令タイムアウトを扱える。[S4]

車輪オドメトリとIMUの統合には`robot_localization`を候補とする。[S5] 上位計算機とセンサーを追加して地図・自己位置推定・Nav2へ進む。ROSディストリビューションやJetson型番はここで固定しない。

設計寸法の原点は車体中心だが、差動駆動の運動学の基準は車軸中央である。`base_link`等の基準座標を選ぶ際は、両者の90mmオフセットをURDF/TFへ正しく反映する。車体中心にあると仮定してオドメトリ・旋回を設定しない。

Nav2の`Collision Monitor`はセンサー情報を使う補助停止・減速層として検討する。[S6] 床際の障害物、段差、透明面、人・ペットとの接触をすべて検出できるとは扱わず、ハードウェア停止経路を残す。

アーム搭載後は「移動時は収納確認」「操作時は車輪停止・保持確認」という相互排他を下位制御にも設ける。学習モデルを導入しても、この制限と停止経路は迂回させない。

## 9. 製作・検証の順序

| 段階 | 実施すること | 次へ進む前の確認 |
|---|---|---|
| 0：室内・部品配置 | 通路・旋回・収納寸法の確認。モーター、電池、キャスター、保持機構のCAD配置と重量積上げ | 外形500×400内、台車10kg以下、部品干渉・電池脱着・配線が成立 |
| 1：台車の試作 | 車輪浮かせ試験→無積載0.15m/s以下→固定した運搬物2kg | 異常停止、意図しない再始動なし、固定・支持・発熱・床への影響が許容内 |
| 2：制御・記録 | エンコーダ/電流ログ、ROS指令、オドメトリ校正 | 実測車輪径・間隔・座標が一致。通信途絶と指令制限が動作 |
| 3：自律移動 | 重量枠内で計算機・センサーを追加 | 複数方向の停止距離、障害物検出範囲、監督下での動作を確認 |
| 4：アーム搭載 | 全姿勢の荷重・干渉・転倒解析後に、許可した小負荷から試験 | 把持重量・姿勢・作業範囲・保持成立を個別に確定 |

将来の最大構成試験は総質量だけでなく重心も再現し、試験治具で転倒・落下を防ぐ。旧版の34〜40kgを載せる試験は実施しない。最大構成14kgは設計計算枠であり、台車が完成しただけで自動的に載せてよいという意味ではない。

強度・停止・保護の検証前に、家庭内で無監督運用しない。軽量化のために非常停止、配線保護、挟み込み防止、電池保護を削除しない。

## 10. 未決定事項・次に確定するもの

| 項目 | 現状・確定方法 |
|---|---|
| 家庭内への適合 | 通路幅、曲がり角、収納高、床の実測が必要 |
| モーター・減速機・エンコーダ | 第一案FIT0185。連続トルク・最低電圧性能・寸法差・発熱の実測が必要 |
| 車輪支持・保持機構 | 独立8mm軸＋各輪KP08×2を配置。車輪等の許容荷重と保持機構は未確定 |
| 締結金具・プレート | 第一案の数量・板厚・穴位置をCADへ反映。購入品の実寸、ミスミ6シリーズとの実嵌合、接合強度は確認待ち |
| 電池・保護・ドライバー | 保護成立、回生時電圧、質量・脱着スペースを確認 |
| アーム・把持重量 | 系全体2kg以内で全軌道の到達・干渉・転倒条件を検証 |
| 調達金額 | 第一案の確認済み機械部品24,409円。板材・追加ねじ・送料枠込み34,159円、加工外注枠込み40,159円。電装・ガード・アーム別 |

**直近の設計確定点は、500×400mm・台車10kg以下で費用を抑え、駆動/保持・電池配置を成立させること。** 第一案の機械部品表とCADは作成済み。電装を含む完成部品表、製作承認図、URDFは未作成。

## 11. 同梱ファイルと再計算

| ファイル | 内容 |
|---|---|
| `DESIGN.ja.md` | 本設計書 |
| `design_parameters.json` | 単位と未確定事項を付けた計算入力。把持上限は`null` |
| `check_design.py` | 重量、外形、旋回、駆動力、梁たわみ例、静的支持領域を計算 |
| `calculation_results.json` | 同梱入力による再計算結果 |
| `test_check_design.py` | 計算関数、制約、旧前提の混入を確認するテスト |
| `CHANGELOG.ja.md` | v0.1からv0.4.1までの変更点 |
| `TEST_RESULTS.txt` | 計算・設計方針・定尺組立と購入数量のテスト出力 |
| `README.ja.md` | 実行方法とファイルの役割 |

設計書の配布ZIPは上記8個のテキスト・計算ファイルのみを収録する。第一案CAD・部品表・実CAD画面はGitHubのcad/amr01に別置する。GitHubでは本設計書を`docs/amr-01/DESIGN.ja.md`、ZIPを`archives/amr_v0_4_1.zip`に配置する。

Python 3.10以降の標準ライブラリのみを使用する。

```bash
cd amr_v0_4_1
python3 check_design.py
python3 -m unittest -v test_check_design.py
```

入力値を変更する場合は`design_parameters.json`を編集して再実行する。設計書の表は自動更新されないため、結果が変わったら本文も同じ版として更新する。計算テストの合格は実機安全性の認定ではない。

## 参考一次資料

参照日：2026-09-20。フレームの購入候補は4.1節で決定。その他の参考資料を部品の採用決定とみなさない。

**[S1] Amazon・ミスミ：NFSL6-3030-300 / NFSL6-3030-400。** 採用材の寸法・断面定数・材質・質量・購入単位・価格。
https://www.amazon.co.jp/dp/B0DKDZ8G9G
https://www.amazon.co.jp/dp/B0DKF2CCW3

**[S2] Makita：STAR Protection説明。** 公式ドメインの検索結果にある工具と電池間の保護通信の説明を確認。特定電池の保護回路・2端子流用時の仕様は未取得。  
https://makitatools.com/

**[S3] Dimension Engineering：Sabertooth 2x32 regenerative dual motor driver。** 回生型ドライバーの参考。採用部品ではない。  
https://www.dimensionengineering.com/products/sabertooth2x32

**[S4] ros2_control：diff_drive_controller。** 差動駆動の指令変換、フィードバック、制限、指令タイムアウト。  
https://control.ros.org/jazzy/doc/ros2_controllers/diff_drive_controller/doc/userdoc.html

**[S5] Nav2：Smoothing Odometry using Robot Localization。** 車輪オドメトリとIMU等の統合。  
https://docs.nav2.org/rolling/configuration_and_development/first_time_robot_setup_guide/odom/setup_robot_localization/

**[S6] Nav2：Collision Monitor。** 近傍センサーを用いた速度制限・停止の補助層。  
https://docs.nav2.org/rolling/configuration_and_development/configuration_guide/core_servers/collision_monitor/

**[S7] MISUMI：アルミフレーム強度目安表。** NFSL6-3030の断面定数と梁計算条件の参考。完成台車の可搬定格ではない。
https://jp.misumi-ec.com/special/alumiframe/tech/capacity_guideline/

**[S8] MISUMI：8シリーズ・40×40mm。** 比較用HFSL8-4040の断面定数・材質・単位質量。購入対象ではない。
https://jp.misumi-ec.com/vona2/detail/110302689860/

## 12. 第一案CADと購入部品（v0.4.0）

[CAD資料一式](https://github.com/sige0002/amr-pj/tree/main/cad/amr01)にFCStd、STEP、部品表、実画面PNG、再生成コード、検証結果を収録する。フレームは300/400mm定尺のまま。FIT0185×2、直径100mm駆動輪×2、独立8mm軸×2、KP08×4、6→8mmジョーカップリング×2、ハンマー420G-R50×1、必要な取付板・ガセット・締結部品を配置した。

フレーム下面は床から75mm、機械骨格の外形は約460×394×115.6mm。将来の電装・ガード・アームを含む外形と高さは別に検討する。駆動輪とキャスターの床面接触、主要67部品の公称形状2,211組の干渉、駆動固定部の地上高26.2mmを確認した。購入品の未公開寸法は仮モデルのため、製作前の実測が必要。

FIT0185は83rpm無負荷、45kgfcm拘束トルク。連続定格の確認はできていない。65rpmを暫定指令上限とし、初期0.15m/s・0.3rad/sの同時指令（外輪38.8rpm）を試験する。後期目標の0.3m/s・0.6rad/sは同時指令できず、`|v|+0.177|ω|≤0.3403m/s`で制限する。機械部品を選定したことは、可搬2kg・坂道走行・10kg以内の実測完成重量・連続運転の認定ではない。

部品代24,409円は購入ページの確認値。素材・追加ねじ予算5,900円、送料予算3,850円を加え、自加工の現金支出目安34,159円。外注加工は正式見積未取得の追加枠6,000円で、合計40,159円。10%予備費込みでは約3.8万円／4.5万円となる。自加工は工具を持っている前提で、工具新規購入と自分の作業時間は含まない。

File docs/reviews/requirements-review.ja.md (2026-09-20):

# 第二案レビュー：要求・費用・製作性

2026-09-20。要求・費用担当の独立レビュー。第一案の[設計値](../amr-01/design_parameters.json)、[CAD生成コード](../../cad/amr01/build_chassis.py)、[BOM](../../cad/amr01/BOM.csv)、[締結部品表](../../cad/amr01/fasteners.csv)を確認した。以下は設計判断であり、完成機の強度認定ではない。

**先行してCAD化する候補は、低い同軸駆動を維持し、車輪を内外の軸受で挟み、金属の箱形支持から3030の上面・側面へ荷重を流す構成。** モーター上置きは比較案に残す。外周材の全面大型化より、車輪支持と接合部へ費用を配分する。

| 区分 | 第二案での扱い | 理由・確認方法 |
|---|---|---|
| 必須：調達・骨格 | Amazonで個人購入できる3030の300/400mm定尺。460×300mm、400mm×4本・300mm×2本、材の切断なし | ユーザーが選んだ調達条件を維持。板・軸の加工まで禁止した条件ではない |
| 必須：質量 | 台車は電池・電装込み10kg以内。荷物2kg、将来アーム系2kgは別枠、最大構成14kg | 10kgは上限であり目標質量や安定用バラストではない。アーム取付板・専用電源も別枠へ計上 |
| 必須：費用比較 | 第一案の自加工34,159円／外注枠込み40,159円と、同じ範囲・購入単位で比較 | 電池・電装・ガード・アームは第一案費用に含まれない。**ユーザーから絶対予算の指定はない** |
| 必須：設計の目的 | 意匠用外装を追加せず、車輪荷重経路・整備性を改善 | 箱形の構造板、端子保護、必要な回転部ガードは機能部品 |
| 優先する選択 | ミスミ純正6シリーズ接合部品、金属の主荷重経路、既存購入候補の再利用 | 純正金具の個人購入経路・送料は未確認。安価な互換品への再変更は適合確認と費用を併記 |
| 軟らかい目標 | 長さ500、幅400、高さ160〜180mm。第二案の跨ぎ支持では幅420mmを比較目標にする | 外壁だけで幅404mmとなる代償。幅420で通路に適合したとは扱わない |
| 設計仮定 | 初期は乾燥した水平な硬い床、0.15m/s。坂5°は選定計算条件 | 最大構成14kgでは余裕込み必要輪トルク約0.708N·m/輪。FIT0185の連続トルク確認・負荷試験は残る |
| 未確定 | 床の段差、通路幅、アーム機種・把持質量・方向、電池・計算機 | 運搬物2kgから「2kgを腕で持てる」と決めない。段差未定のままサスペンションを追加しない |

第一案は8mm軸をKP08二個で支持し、モーター軸から車重を逃がしている。ただし軸受間隔27mm、外側軸受から車輪中央まで32mmあり、車輪は二個の軸受の外側に張り出す。輪荷重を仮に100Nとした静的モデルでは軸受反力は約−119/+219Nとなる。これは実輪荷重ではなく形状比較である。さらにt4支持板を40mmの丸スペーサ四本で吊り、横力・駆動反力に対する接合部の剛性が未確認。**「3030全体が弱い」とは結論できず、箱形化の効果を先に評価する根拠がある。**

| 候補 | 荷重・配置上の利点 | 費用・製作上の代償 | 判断 |
|---|---|---|---|
| 第一案のまま | 既存CAD・BOMを利用 | 長いスペーサ、外側張り出し、軸端ガード片側3mmを残す | 比較基準 |
| 低い同軸＋箱形、従来の片持ち車輪 | フレーム高さ・輪距を維持しやすく、支持板の横揺れを改善 | 箱板・短い金具を追加。軸の曲げと大きい外側軸受反力は残る | 最小費用の比較案 |
| **低い同軸＋箱形、車輪を内外軸受で挟む** | 車輪支持スパン内へ荷重を置き、モーターと支持機能を分離。上面・側面の二面締結が可能 | 軸受・壁・軸方向保持の再設計。輪距354→340mm、完成幅400→420mmを比較する | **先行CAD案** |
| 上置きモーター＋独立支持軸＋ベルト | 床近くのモーターを移動でき、フレーム高さ75〜105mmを維持する配置案もある | 上軸・軸受・プーリー・ベルト・張力調整・ガードが追加。上置き担当の増額仮枠は0.8〜1.5万円、正式見積なし | 下部スペースの不足が確認された場合の代替案 |

上置きで強くなるのはモーターの高さそのものではなく、支持方法を改める効果である。FIT0185の出力軸にベルトを直接掛けると、車重を分離しても張力によるラジアル荷重が残る。上置き担当は上軸も二点支持する案を提示したため、この追加費用を省いた比較にはしない。無負荷83rpmのモーターをさらに減速する場合は最高速も下がる。

車輪支持担当が提示した跨ぎ支持の初案には、フレーム嵩上げと輪距縮小の代償があった。要求担当は高さ・重心・キャスター台座を同時変更しない案を求め、統合案ではフレーム下面75mm、車軸x=90mm、50mmキャスターを維持した。輪中心y=±170mm、内壁105〜109mm、外壁198〜202mm、上板z=105〜109mmを候補とする。公称隙間はタイヤから側面金具へ4.3mm、3030本体へ7.3mm、上側5mmで、現物の幅・振れ・変形、ねじ頭、配線、ガードを含めて判定する。外側壁を外す手順、車輪・ハブの抜き方向、工具の進入もCADで示す。

支持点数は駆動配置と分けて決める。**平床の初期機は二駆動輪＋一キャスターを維持**し、支持三角形の全方向で実重心を照合する。三点支持は四点を剛に固定する構成より床のねじれに対して接地を保ちやすい一方、後方・横へのアーム伸長余裕が小さい。二駆動輪＋二キャスターは支持領域を広げられるが、四点剛支持では床や組付け誤差で一部輪の荷重が減るため、揺動・ばね・高さ調整と駆動輪荷重の検討を併せる。

既存機から採り入れるのは構成原理である。[Create 3公式資料](https://iroboteducation.github.io/create3_docs/hw/mechanical/)は差動二輪の独立懸架と三点支持、重心変化に応じた後部キャスター追加を示す。[TurtleBot 4公式資料](https://turtlebot.github.io/turtlebot4-user-manual/mechanical/payloads.html)も荷物の低配置と支持範囲を重視する。したがって「キャスター追加だけで安定」という読み方はしない。

[Waveshare UGV Rover公式資料](https://www.waveshare.com/wiki/UGV_Rover_PI_ROS2)は六輪・四輪駆動と2mmアルミ筐体を採用している。板を折り曲げた箱構造を荷重経路として使う考え方は参考になるが、同じ板厚だけで本機の14kgに適合したとはいえない。[タミヤTT-02公式資料](https://tamiya.com/english/products/58743/index.html)はバスタブ形フレーム、シャフト駆動4WD、四輪ダブルウィッシュボーンを明示する。左右共通部品や保守可能なユニット構成を参考にし、部品の耐荷重や高速RC用懸架をそのまま転用しない。

純正接合部の参考数量は、元の八接合ならHBLFSN6-SET×8。SETは一組にCBM6-12×2、HNTT6-6×2を含む。公式の2026年7月価格表は本体78円＋SET追加97円＝税別175円/組、八組の税10%換算は1,540円となる。[ミスミ公式規格・価格表](https://jp.misumi-ec.com/vona2/detail/110300442340/)。元BOMの溝ナット40個と比較するには、追加24個と不足ボルト・ワッシャが必要。[HNTT6公式ページ](https://jp.misumi-ec.com/vona2/detail/110302610850/)の旧価格表には2023年4月時点と明記されるため、最終金額は型番・数量で再確認する。純正八組だけを旧セット2,580円と比較して「安くなった」と結論しない。第二案の二面締結で増えるナットも別計上する。これはメーカー参考費でありAmazon販売確認や個人向け確定見積ではない。

製作は矩形板・市販アングル・通しボルトを基本とし、長穴、曲げ、精密な軸受穴、軸の平面加工、車輪の穴加工を加工費から落とさない。二軸受は同軸に組み、軸方向は一方を位置決め・他方で誤差を逃がす構成を検討する。過剰な締付けで回転が重くなる組立を許容しない。

P1Sの公称造形域は**256×256×256mm**で、280mm角ではない。[Bambu Lab公式P1S仕様](https://us.store.bambulab.com/products/p1s?country=US&currency=USD&variant=41929890365576)。PLAは穴位置確認治具、配線保持、センサー台、局所ガード、機器トレイの位置決めに使う。軸受の主支持、車軸の締結、モーター反力を受け続ける台座は金属を基本とする。PLAの荷重たわみ温度は試験条件依存であり、その数値を連続使用可能温度とみなさない。[メーカーPLA Basicデータシート](https://store.bblcdn.com/s7/default/b189de92249a4b9ebed28b8ea1f080f0/Bambu_PLA_Basic_Technical_Data_Sheet.pdf)。分割造形して車体を覆う大型外装は今回の要求に含まれない。

設計を進める判定点は、全接地点と重心、車輪からフレームまでの荷重経路、回転体の公差込み包絡、脱着手順、購入単位を含む差額の五つ。CAD干渉検査を通過しても、連続トルク・温度、軸受やハブの滑り、段差衝撃まで確認できたとは扱わない。

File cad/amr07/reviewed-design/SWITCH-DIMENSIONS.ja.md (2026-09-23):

# スイッチ寸法の照合とCAD訂正

2026-09-23。部品の公開寸法を調べ切らず、一括して「現物確認待ち」とした説明を訂正する。購入型番が決まっていることと、設計側の寸法調査が完了していることは別であり、今回の不足は設計側にあった。

| 対象 | 公開資料で確認できた値 | CADへの対応 |
|---|---|---|
| amon3214 | 正面19.5×30.5mm、取付面から表側21.5mm、裏側端子先まで28mm、穴φ12、板厚1〜4mm、250型メス接続 | 仮円柱の表側を外形包絡へ修正。取付面Z156.4、最高点Z177.9、端子先の基準Z128.4を記録 |
| HW1B-V402R | φ40、表側32mm、2接点の裏側49.4mm、接点41.4×29.4mm、TOP側レバー突出26.5mm | 接点幅を中心対称に訂正し、TOP側レバーを含む保守的包絡へ修正 |
| HW取付穴 | φ22.3〜22.7、キー幅3.2〜3.4、円下端からキー先まで24.1〜24.5mm | φ22.5、幅3.3、全高24.3を採用。以前のキー先位置は浅く、蓋CADとSTLを修正 |
| HW締付部 | HW9Z-LN：φ28.4×5、M22 P1。工具MW9Z-T1：φ28 | 既存E4のナット寸法は一致。工具空間はφ29で確保 |

出典：[エーモン公式寸法入り台紙](https://www.amon.jp/upload/save_image/3214_SUB2_L.jpg)、[公式固定説明](https://www.amon.jp/upload/save_image/3214_SUB3_L.jpg)、[IDEC作成カタログ p.3〜5（販売店配布）](https://www.tdcjapan.com/wp-content/uploads/2017/06/P5204A-HW-with-RemovableContactBlock.pdf)。[機械可読の値・資料ハッシュ](switch-dimensions.json)も記録した。

3214用の蓋穴は既存のφ12.2を維持している。メーカー指定の公称φ12に対し直径0.2mmの試作造形クリアランスであり、メーカー公差ではない。造形寸法を校正し、過大穴や固定の緩みがあれば修正する。

3214の表側は外接直方体による干渉判定用モデルで、ロッカーの曲面を再現したメーカーCADではない。裏側28mmは端子先までの寸法で、メス端子を挿した後の寸法ではない。既存端末確保空間Z123.4〜140.4はこの端子先を含むが、端子ピッチ・個々の刃長・樹脂ナット外径/厚みは参照台紙に数値がない。図の画素比から保証寸法を作らない。裏側の細部は依然として仮の配置形状であり、全寸法確定とは扱わない。

[IDEC公式商品ページ](https://www.idec.com/ja-jp/switches-indicator-lights/switches-pushbuttons/emergency-stop-switches/hw-22mm-estop/hw1b-v402r)には寸法図HW1B-V4-A4-A05265C.pdfとSTEPが登録されている。今回、寸法図の取得経路はHTMLページを返し、STEPはログイン対象のため取得していない。参照カタログで端子位置の図示は確認できるが、ねじ中心座標の数値は未取得。この不足も「現物がなければ分からない」とはしない。

残る事項は次の3種類に分ける。

- **資料取得不足**：3214のナット詳細、HWの端子中心・ラッチ詳細。追加のメーカー図面取得で解消する対象。
- **部品未選定**：250型の絶縁メス端子または端末加工済みリード。スイッチとは別の購入部品であり、型番と外形を決める必要がある。
- **製作・実機の検証**：PLAの造形公差と長期締付保持、完成配線の取り回し、実負荷の遮断。公開外形寸法とは別の検証対象。

標準案・モニター案のCAD、保存STEP、画像、試作ZIPを更新し、干渉・整備空間を再検査済み。取付部品を購入して測ることを、公開情報調査の代わりにはしない。

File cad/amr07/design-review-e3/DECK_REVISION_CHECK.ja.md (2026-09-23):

# 標準天板改訂案：強度と極低頭ボルトの簡易再レビュー

2026-09-23。独立AIレビューの追補。以下の指定寸法に対する計算であり、変更後CADの干渉合格・実物強度・車体全体の安全率達成を認証する文書ではない。CAD・BOMは編集していない。

## 対象と結論

300×300×4mm、6061-T6・耐力240MPa以上という既存調達条件を維持する。中央格子はXY各−100,−50,0,50,100のφ4.5通し25穴。天板固定はX=−125,0,125、Y=±135のφ6.6通し6穴。ベルト長穴は全長30×幅6、端R3で、(X±140,Y0)は長手Y、(X0,Y±110)は長手X。常設ストッパを撤去し、固定ねじをNBK SSH-M6-12へ変更する。皿加工は行わない。

**この変更で板厚を増す必要を示す結果は出ていない。** 通常荷物10kg、静的比較15kg・荷重係数2の条件に対し、大局的な曲げは採用を継続できる比較値。ただし、ベルト長穴まわりの荷締め張力、局所穴応力、座面・溝ナット、レール接触、実ねじの保持は別の確認を残す。通常10kgは引き続き実機確認前の設計目標で、15kg走行定格へ拡大しない。

## 1. 穴配置と断面

| 確認項目 | 指定形状からの結果 |
|---|---:|
| φ4.5穴の隣接間隔 / 穴間残肉 | 50 / 45.5mm |
| 格子最外穴から板端までの残肉 | 47.75mm |
| M6穴中心から近いY板端 | 15mm |
| M6穴端からY板端までの残肉 | 11.7mm |
| 頭径10のボルト外周からY板端 | 10mm |
| X±140長穴の外側から板端 | 7mm |
| (0,±100)格子穴とY±110長穴の最短残肉 | **4.75mm** |
| Y=0断面のX方向金属幅合計 | 300−5×4.5−2×6＝265.5mm |
| Y=±100の格子穴行の金属幅合計 | 277.5mm |
| Y=±110長穴中央断面の金属幅合計 | 270mm |

最小肉4.75mmは丸穴と長穴の間で、外形板厚4mmと同程度。梁計算が通ることを理由に、長穴へ任意の大きさの締付張力を与えてよいとはしない。中央格子は上段レール内端Y±120より内側にあり、旧案の「一列だけ溝ナット」という違いを解消できる。

指定切欠きの理論平面積は88,708.02mm²、密度2,700kg/m³で板質量0.95805kg。穴面取り・角部仕上げは含まない。以下では切り上げて自重1kgとし、板の荷重評価に含めた。最終BOM質量は変更後CADから照合する。

## 2. 板の大局曲げ

既存レビューとの比較のため、幅300mmの半分に相当する有効幅b=150mm、厚さt=4mmの単純支持梁へ置き換える。弾性率E=69,000N/mm²、断面二次モーメントI=bt³/12=800mm⁴、断面係数Z=bt²/6=400mm³。実際の穴あき板の荷重拡散を保証するモデルではなく、有効幅の仮定を含む一次比較である。

上段レールの内端間は240mm。支持位置の不確かさを考慮して、さらにレール中心間270mmでも計算する。実支持接触を解析したことにはしない。

荷重は通常(10kg＋板1kg)×g=107.873N、静的比較(15kg＋板1kg)×g×2=313.813N。安全率2を荷重側に入れているので、応力の比較時に同じ係数を重ねて適用しない。

中央集中荷重の場合、M=PL/4、σ=M/Z、δ=PL³/(48EI)。既存条件の中央200×200mm連続平底を、Y方向の中央200mm一様分布へ置き換える場合はa=200として、M=P(2L−a)/8、δ=P(8L³−4La²＋a³)/(384EI)。板自重も中央に集めた荷重へ含める。

| 荷重ケース | 支持間L | 中央点荷重：応力 | 中央点荷重：たわみ | 中央200mm分布：応力 | 中央200mm分布：たわみ |
|---|---:|---:|---:|---:|---:|
| 通常10kg＋自重1kg | 240mm | 16.18MPa | 0.563mm | 9.44MPa | 0.408mm |
| 通常10kg＋自重1kg | 270mm | 18.20MPa | 0.801mm | 11.46MPa | 0.622mm |
| 静的15kg＋自重1kg、係数2 | 240mm | 47.07MPa | 1.637mm | 27.46MPa | 1.187mm |
| 静的15kg＋自重1kg、係数2 | 270mm | **52.96MPa** | **2.331mm** | **33.34MPa** | **1.810mm** |

最大比較応力52.96MPaは調達耐力240MPaを下回る。これは穴周りのピーク応力・接触・ボルト座の保証を含まないため、240/52.96を車体全体の達成安全率とは表示しない。たわみを1mm以内などに制限する機器を搭載する場合は、現行貨物条件より厳しい要求として別評価する。

点荷重ケースは梁全体の曲げ比較であって、小さな脚・鋭利な接触点の局部押込みを認めるものではない。荷物条件は従来の中央200×200mm平底を維持する。穴数削減だけを根拠に強度が上がったと断定せず、長穴の位置変更も含めて確認する。

## 3. SSH-M6-12の選定に伴う注意

[NBKメーカー寸法・材料資料](https://static.nbk1560.com/images/ja-JP/product/lowsmallheadscrew/SSH/SSH_1.pdf)では、M6は頭径10mm、頭高さ1.5mm、六角3mm、最大締付トルク参考値6.3N·m。材質SCM435、ねじ部10.9に対して頭部は5.8相当であり、頭部が弱い旨の注意がある。**6.3N·mは参考上限で保証値でもこの台車の推奨締付値でもない。通常のM6キャップ用トルクを流用しない。** メーカーはこの締結構造の許容積載重量を示していない。

M6×12の首下長さは従来と同じ。頭の座面を板上面Z233へ置けば先端Z221、板下面Z229からレール内へ8mm突出する。公称溝底余裕約1mmは継承できる。頭上端はZ234.5となり、旧Z239より4.5mm下がる。完全な面一ではないが、中央格子領域から外れた周辺帯へ突出を限定できる。

頭径は旧簡略モデルと同じ10mmで、φ6.6穴を囲む公称環状座面はπ(10²−6.6²)/4=44.33mm²。これを全て有効とみなした一次面圧比較を行う。実際の首下R・端面面取り・穴面取りを含む接触面積はこれより小さくなり得る。

締付軸力をF=T/(Kd)、d=0.006m、摩擦を表す仮定K=0.15～0.25とすると：

| 締付トルク | 推定軸力範囲 | 公称平均座面圧範囲 |
|---|---:|---:|
| 2.0N·m（評価候補） | 1,333～2,222N | 30.1～50.1MPa |
| 3.0N·m（比較） | 2,000～3,333N | 45.1～75.2MPa |
| 6.3N·m（メーカー参考上限） | 4,200～7,000N | 94.7～157.9MPa |

Kは実測値でない。軸力散らばり・座面局部塑性・溝ナット引抜き・ボルト頭部の曲げが残るため、上表から最終締付値を確定しない。2.0N·m付近を実物評価の候補にし、座面変形・保持・緩みを確認して作業値を決める。潤滑剤を追加すると同じトルクでも軸力が変わるので、この比較のまま潤滑条件を変えない。

下向き貨物荷重は2本のレール上面との接触で受け、ねじ6本で荷物重量を吊り下げる構造ではない。頭強度低下を無視してよいという意味でもなく、ベルト反力・上向き荷重・持上げ時の力・走行振動について締結部の検証が必要。荷物をつかんで車体を持上げる用途は承認していない。

## 4. CAD変更後に設計担当が確認する事項

1. 新しい固定点で、頭・溝ナットが支柱/上段ブラケット/他の溝ナットと衝突しない。特にX±125では以前のX±105との比較が必要。
2. 格子全25穴へM4ボルト・ナット・工具を置き、1階機器・電池への突出を確認する。長穴を通すベルトがレール上端や角で擦れない。
3. ボルトの実長・板厚公差・ねじ入口の面取りを含め、有効ねじ掛かりと溝底余裕を確認する。単なる公称ソリッド重なりを有効ねじ長さと同一視しない。
4. 荷締めに用いるベルト/バックルと初期張力を決め、長穴端・4.75mm残肉・板の局所曲げを評価する。現計算は荷締め張力を含まない。
5. 実板に通常荷重、静的比較荷重を段階的に与え、変形・除荷後の残留変形・固定点の緩みを確認する。これを実施するまで運転定格を引き上げない。
6. 31丸穴・4長穴となる新STEPで見積を取り直す。旧価格は参考として区別し、新形状へ同額を転記しない。

本追補での再判定は「4mm板と外周6点の極低頭固定を、既存10kg通常条件の試作候補として継続可能」。実物受入れと変更後CADの検証は未実施である。

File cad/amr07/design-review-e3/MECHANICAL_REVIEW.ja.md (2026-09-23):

# E3 機構設計レビュー

2026-09-23。依頼に基づく独立したAI機構設計レビュー。設計者による認証・実機試験の代替ではない。CADを読み取り専用で調査し、本設計は変更していない。オプションモニターは対象外。

対象：`pico-control/AMR01_PicoControl_E3.FCStd`、SHA256 `e1bf029a1e561db21e92fb612d61351cf53859e1ed97b6490797612825c05d55`。E3の作成・検査コード、D6.9天板図面・加工見積・要求仕様も照合した。

## 結論

3030骨格と二階構造を作り直す根拠はない。電池取り出し口を挟んだ左右分離スイッチ、PLA床へ支持させる構成、天板の左右レールへの6点固定は継続できる。改善すべき中心は、**スイッチの実際の取付部品と配線を含む組立成立性、天板中央の使いやすさ、留め具による荷面の突出**である。

現在の「新規干渉なし」はモデルに含まれる部品同士の結果。未モデルのロックナット、端子、圧着端子、工具の進入・配線曲げを確認済みとは読めない。これらを入れた上で小型化するべきで、箱を小さくすること自体を先に目標としない。

## 修正を強く勧める項目

### M-01：スイッチの締結部品・端子・組立順が未完了【高】

**観測根拠**：非常停止は参考包絡モデル、主電源は円筒包絡モデルで、実ロックナットと250型平端子がない。主電源の蓋裏リブ内面はX=−213と−181、スイッチ中心X=−201なので、片側半径方向の空間は12mmしかない。箱外形66×44×44mm、蓋3mm。非常停止は66×76×66mm、蓋5mm、リブ内面間34mm。

メーカー資料では、HW9Z-LNナットはφ28.4×高さ5mm、MW9Z-T1工具はφ28。非常停止の既知径はリブ間へ収まるため、「ナットが確実に干渉する」とは判定しない。一方、主電源は実ナット外形を確認していない。エーモンは3214のφ12穴・板厚1～4mm・250型メス端子を指定している。[IDEC資料](https://www.tdcjapan.com/wp-content/uploads/2017/06/P5204A-HW-with-RemovableContactBlock.pdf)、[エーモン公式](https://www.amon.jp/products2/detail.php?product_code=3214)

**原因**：電装外形から箱を作り、固定部・ハーネス・工具を後回しにしている。

**具体修正**：スイッチ本体、ナット、端子を別部品にし、まず主電源の中心をリブ間中央へ合わせるか、リブをナット周囲で逃がす。非常停止の標準工具通路も形状化する。蓋を外して机上で「操作部を挿入→ナット締付→接点装着→端子配線」を行い、その後に蓋を箱へ戻せる構造とする。側面ポートの内側に結束点を設け、箱を開けるための配線余長を確保する。

**必要検証**：実ナット/端子公差、工具全長・径、接点ブロック脱着方向、蓋の持上げ経路と配線曲げ。CADで一括した参考包絡物を衝突判定から除外して済ませない。実寸不明の主電源を無理に確定形状とせず、必要空間と未確認寸法を分けて記録する。

### M-02：天板上の常設ストッパとボルト頭が汎用荷台を妨げる【高・使い勝手】

**観測根拠**：天板はZ229～233mmだが6本のM6頭はZ239mmまで突出する。ストッパ4個は上面から15mm突出し、X方向の内面が±102mm、Y方向も±102mmで、約204mmの内側領域を形成する。300×300mmの板に広い箱・拡張ベースを置く際に、中央ストッパが先に当たる。

**原因**：過去の一定寸法荷物用の位置決め具を汎用荷台に常設している。

**具体修正**：4個のストッパを着脱オプションへ分け、標準CADの荷面から外す。固定穴も専用8穴を維持する理由を見直し、格子穴を使う位置調整式ストッパへまとめる。貨物固定用ベルトは別途必要で、ストッパを貨物拘束の代わりとしない。

天板固定は3本/レールの6点を維持し、X=−125、0、125、Y=±135mmなど外周作業帯へ寄せる案を比較する。ただし支柱・上段ブラケット・溝ナットとの衝突確認が前提。M6の低頭ボルトを候補にし、中央荷面へ頭を置かない。4mm板を皿加工して平らにする案は、薄い残肉と加工費を増やすため第一候補にしない。

**必要検証**：購入できる低頭ボルトの頭径/高さ/六角サイズ/強度区分、首下長さと溝底余裕、上からの工具直進域。板の端距離、溝ナットとブラケットの干渉、締付座面圧を再計算。低頭化しても完全な平面にはならないため、「中央有効荷面」と「外周留め具領域」を図に明示する。

### M-03：天板の穴配置が旧下段レールに依存し、拡張用の基準が不統一【中～高】

**観測根拠**：実CADの36個φ4.5穴はX=−125,−75,−25,25,75,125、Y=−115,−65,−15,35,85,135mm。50mmピッチだがY方向+10mmの偏りがある。Y=135の6穴のみ上段3030上面溝に重なり、他の30穴とナット方式が違う。中央原点には穴がない。長穴もX側はY=10、Y側はX=60で対称性がない。

**原因**：旧D3の下段直置き支持との干渉を避けた形状を、そのまま上段へ移したため。単純にYを±125へ対称化すると、上段レールの溝中心±135から10mmずれた材部に重なり、下面ナットを置けない。

**具体修正**：上段の現在の支持条件で穴配列を再設計し、フレーム締結と拡張穴の領域を分離する。

| 案 | 中央領域 | 格子穴数 | 評価 |
|---|---|---:|---|
| 拡張性優先 | X/Yとも−100～100mm、25mmピッチ | 81 | 原点穴があり25/50/75/100mmの取付間隔へ対応しやすい。左右レール上の穴を避ける |
| 低加工費優先 | X/Yとも−100～100mm、50mmピッチ | 25 | 穴数を抑え、必要な小物は安価なPLA変換板で対応。細かな位置調整には弱い |

モーターの特殊固定を除く拡張小物は、PLAアダプターで寸法を変換する方針と相性がよい。25mm格子でも市販機器全ての穴位置に一致するわけではない。ベルト長穴は対向位置をそろえ、取付穴・レール・ねじ頭と干渉しない位置へ配置する。

**必要検証**：全穴に実M4ねじ/ナット/工具を置く確認、組付けた小物下面とPC・電池の隙間、板の穴あき断面/たわみ。81穴に増やしても追加45穴の金属除去は約7.7gにすぎず、軽量化のための加工とは言えない。穴・長穴を変更すると旧JLCCNC見積38.65USDは現形状の価格でなくなるため、変更後STEPで実見積を取り直す。穴数から加工金額を推定して確定額にしない。

### M-04：PLA蓋の押下強度と固定ナットの長期保持は別の検証【中・試作前に明記】

**観測根拠**：E3の150N簡易梁計算は7.05MPa、たわみ0.189mm。これは指定した短期材料値による曲げ評価。IDECのナット推奨締付は2.0Nmであり、PLAへの持続圧縮、回り止め切欠きの局部負荷、熱とクリープは含まれていない。非常停止の底板は7mm、床上座8mm、4本M4で支持され、片持ち箱ではない。

**具体修正**：箱全体を金属化する必要性は示されていない。まずナット座を平坦・連続にし、締付け箇所とリブの荷重経路を明示する。メーカー指定板厚以内で局部厚さを確保し、専用工具が入る空間を残す。必要なら既製の適合座金/パネルを追加するが、未知の寸法で金属板を自作追加して対策済みにしない。指定締付を下げるだけの回避もしない。

**必要検証**：採用PLA、造形方向・壁数を定め、指定締付後の保持、繰返し押下/復帰回転、実使用温度での放置後の緩みを試験する。保持不足が出た場合に交換可能な小さな金属操作面または既製箱へ移行できる構成とする。金属操作面を採用する場合も追加加工・送料をBOMへ反映する。

## 改善候補と維持する設計

| 項目 | 判断と理由 |
|---|---|
| 2個の箱を1個へ統合 | 今回は優先しない。中央は幅75mmの電池と後方取り出し経路であり、大きな一体箱は整備性を悪くする |
| 非常停止箱の高さ | 接点後方深さ49.4mmが支配する。現在はケース内部底Z116.4に対し接点後端Z131、14.6mmの余裕がある。端子・配線を追加する前に削らない |
| 主電源箱の高さ | 円筒の仮外形しかなく「余分」と確定できない。250型端子と曲げ半径を含めて初めて減らせる |
| 床固定4本 | 維持。蓋を外した状態でφ6mm直線工具の進入を各4本、計8本についてCAD確認し、ケースとの干渉0mm³だった |
| スイッチ箱の蓋4本 | 維持。小径ねじの追加やヒンジより、上から同一工具で開けられる現方式が単純。ナットポケットは組立前に挿入する順序を図示 |
| 天板6点固定 | 維持。片側2点などへ安易に減らさず、荷面を妨げない頭形状/位置で改善する |
| 軽量化 | 車体10kgは厳密条件でなく、72g増だけを理由に支持部を削る必要はない。ストッパのオプション化は重量と使い勝手を同時に改善できる |
| 加工費 | ねじ無し通し穴、丸穴の径統一、長穴の端R統一を継続。穴配列変更の実見積を取るまでは従来価格と同等とは書かない |

## 変更後の受入条件

1. スイッチ固定部品と端子を形状化し、箱・蓋・工具・配線を含めた組立手順が成立する。
2. 天板中央に常設ストッパを置かず、拡張穴の原点・ピッチ・対応締結方法・外周作業帯が図面で分かる。
3. 6点の天板固定、4点の各箱固定、電池の8mm持上げ＋後方220mm取り出しを保持する。
4. 穴配置変更後の板強度、部品/工具の干渉、見積形状との同一性を再確認する。
5. 実物寸法未確認部分と試験未完了部分を、CAD完成やBOM完成という言葉で隠さない。

設計変更の優先順はM-01→M-02/M-03→M-04の実物試験準備。全面再設計ではなく、現在の骨格と電池アクセスを維持する局所修正を推奨する。

## 追補：設計担当からの皿M6・中央25穴案への回答

レビュー提出時に、設計担当から「中央X/Y±100の50mmピッチ25穴、6点固定を維持して天板のみ皿M6、標準ストッパ撤去」が提示された。穴数と変換板の併用を重視する構成として妥当。全面平面を優先するなら、皿固定も以下の条件付き候補とする。初期推奨の低頭固定と異なり、**座面の強度確認と製造形状変更を伴う**ことを判断記録に残す。

- M6という呼びだけでは頭形状が決まらない。[東工舎のTKS皿ボルト資料](https://www.tokosha-k.co.jp/SARAKATA.pdf)の頭径12mm系に対し、[NBKのSNFCS-M6](https://www.nbk1560.com/products/specialscrew/nedzicom/socketheadcapscrew/SNFCS/)は頭径13.44mm・高さ3.72mm。購入する品番と図面を固定し、混用しない。
- 仮に90°・φ12.2皿＋φ6.6通しなら、皿深さ=(12.2−6.6)/2=2.8mm、厚さ4mmの円筒穴部残肉は1.2mm。板厚最小3.9、皿径最大12.3、通し径6.6の条件でも1.05mm残る。これは幾何成立の確認であり、強度保証ではない。φ13.44系を同様に入れると公称残肉は0.58mmまで薄くなるため、今回の板では優先しない。
- 頭を含めた全長12mmの皿M6を天板上面Z233へ面一で入れると、先端はZ221。板下面Z229から8mm突出し、従来M6×12キャップと同じ先端高さになる。長さの呼びはキャップの首下長さと異なる。皿座を深くして頭を沈める分は追加突出になる。
- 既存CADでは突出8mm、溝底余裕約1mmを想定している。M6×15等へ安易に長くしない。購入ねじの長さ公差、皿深さ、公称ナット厚だけでなく実ねじ入口/不完全ねじ/面取りを含めた有効掛かり、溝底までの最小隙間を確認する。
- 皿穴位置は3030上面で支持される外周帯に限定する。板の中央スパンに皿穴を追加しない。座面の引抜き・局部曲げ、締付による板のへこみ、繰返し取外し時の座面変形を評価する。通常荷物の鉛直荷重はレールへの面支持で受け、皿ねじ6本に全重量を吊り下げる説明はしない。
- 六つの円錐座は穴位置の誤差に敏感になる。製造位置公差とレール間隔を確認し、全ねじを緩く入れてから対称順に締め、一本を完全締結して他を無理に合わせる組立を避ける。

この追補は採用部品の発注承認や新板の加工見積完了を意味しない。新品番・新STEP・見積が揃うまでは設計案として記載する。

## レビュー受領後の設計担当の方針

設計担当から、今回は皿加工を採用せず、メーカー資料を確認したNBK SSH-M6-12（頭径10mm、高さ1.5mm、六角3mm）を外周6点へ置く方針が通知された。中央25穴、常設ストッパのオプション化、ベルト長穴の対称化も採用予定。これはM-02/M-03の具体的な対応方針として妥当。形状変更後の干渉・ねじ掛かり・座面・見積確認は設計担当が実施する。本レビューは変更後CADの承認記録ではない。

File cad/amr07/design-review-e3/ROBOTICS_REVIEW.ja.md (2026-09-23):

# E3 ロボット・電装・実運用レビュー

2026-09-23。対象コミット `8341c3798e2f76c1cbd1f697fe2afd32d9ff66c7`、`pico-control/AMR01_PicoControl_E3.FCStd` と関連する配線・BOM・検証資料をレビューした。独立したAIレビューであり、人間専門家の認証・実機試験ではない。本レビュー担当はCAD・BOMを変更していない。モニターは別のオプション設計なので対象外。

最小構成の「全電源用主スイッチ＋左右モーター電源だけを切る非常停止＋Pico/RS485」は維持してよい。スイッチを増やすことより、取付・配線・操作空間と復帰挙動を具体化する方が先。天板は、一段構成の穴位置を継承した結果、二段構成での工具アクセスが揃っていない。

## 優先指摘

P1は通電・走行や部品製作前に解消すべき事項、P2は今回の設計改良で反映したい事項。実機が必要な検証を、CADだけで完了扱いにしない。

| ID | 重大度 | 具体的な根拠と影響 | 今回の変更案 | 完了判定 |
|---|---|---|---|---|
| R1 | P1 | スイッチのモデルは端子込みの概略外形。実際の締付ナット、HW接点固定レバー・付属レバーストッパ、250型絶縁端子と線の曲げを含まない。干渉ゼロでも組み立てられることを示していない | スイッチ固定部・端末・工具の包絡を追加し、蓋を外して締める組立順序を明記。配線口の直近に引張止めを追加。蓋側へ出る配線には取り外し用の余長を設定 | 蓋を外した状態でナットを締結できる、HW接点をロックできる、蓋を閉めても線を挟まない。部品確定前は寸法の仮定を明記 |
| R2 | P1 | HW1Bの各NCを各モーターへ割り当てる理由は妥当。ただしメーカーDC接点定格とモーター約3Aの保護値は、入力突入や接点遮断過渡の適合証明ではない。主電源amon3214も同様 | 接点割当と保護用ヒューズを維持し、未確定の線材・端末・ヒューズを製作表へ分けて表示。機械配置の承認と電装の通電承認を分離 | 完成ハーネス仕様、主電源/非常停止の実負荷適合、ヒューズと最細線の協調を確認。適合すればリレー追加不要。不適合が分かった場合だけ代案を選ぶ |
| R3 | P1 | PCとPicoは非常停止後も通電。PicoにはS1状態入力がなく、短い断電を見逃す可能性がある。モーター内部保護は自動復帰する仕様。現在の「応答異常を検出して新しい開始操作を要求」は必要だが、すべての停止解除後の再始動防止を保証しない | ソフト仕様に「古い指令・USB受信残留を破棄」「左右どちらかの応答異常/故障で両輪指令を禁止」「復帰後はゼロ指令で通信再確立してから明示的な走行開始」を追記。非常停止解除前にPC側で走行を解除する運用を明示 | 車輪浮上で、S1の長短押下、片側断線、PC切断、Pico再起動、モーター故障復帰を試す。未検出の短い電源断は残存制約として記載し、独立した再始動防止を実装済みと書かない |
| R4 | P2 | E3の干渉チェックは変更物と電池経路を対象とし、新HW位置での手の進入を再確認していない。押下、回して解除、主電源操作は異なる動作 | 後ろからの手の進入、上からの押下、回転解除の包絡を別々に追加。赤い面を黄色で囲み、「モーター電源停止」、黒を「主電源・PC終了後OFF」と表示。主電源ON/OFF方向も示す | 荷物・ベルト・配線を含む通常配置で届く。解除時に主電源や配線を誤操作しない。実機での操作性は別途確認 |
| R5 | P2 | 格子穴は50mm間隔だが、X=-125…125に対してY=-115…135と非対称。Y=135の6穴は上段フレーム溝上、Y=-115の6穴はフレーム端に近い。下面工具が入る汎用穴と、溝ナット前提の穴が混在 | 中央を原点にXY対称の格子へ再配置し、中央の拡張穴と外周のフレーム固定穴を区別。全面を細かくする前に、工具の入る36穴程度の案と少数の50mm格子案を比較。ねじ切りを追加する必要はない | 標準M4の頭・ナットだけでなく工具包絡も確認。穴数・穴径・段取りを変更した加工価格は旧見積と分け、安くなると断定しない |
| R6 | P2 | 天板は6本のM6で固定されるが、頭が積載面上へ出る。格子穴、荷物ストッパ8穴、ベルト4長穴、天板6固定穴が別系列で、何を外せば天板が外れるか分かりにくい | M6固定穴は外周に揃え、見分けられる6か所を図示。中央は平坦な搭載範囲にする。荷物ストッパは着脱式の付属品として表示し、常設の15mm突起を汎用天板の必須条件にしない | 代表的な箱と機器取付板を各1例置き、固定ボルト・ベルト・ストッパが競合しない。通常電池交換は天板を外さず可能。ストッパを外した場合も荷物拘束方法がある |
| R7 | P1（配線製作前） | 「はんだ不要」は妥当な方針だが、Picoのヘッダー実装状態、モーターケーブルの完成品、主電源の250型絶縁端子、分岐、ヒューズ、PC給電部材が未確定。CADのケーブルは経路ガイドだけ | 箱に線を通すだけで済ませず、既製ハーネスか端末加工依頼かを各線で区別。モーター電源線と信号線を識別し、戻り線を含む接続表にする。ケースのUSB抜き差しとPico書込操作のアクセスも確認 | 圧着・はんだのユーザー設備を仮定せず組める部品一覧になる。受領するPico/HATのピン高さ・部品干渉の照合後にケース印刷を確定 |

## 天板の独立した読取検証

FreeCADの別headlessプロセスでE3を読取のみ実行した。天板下面Z=229mm、上段3030はY=-150…-120および120…150、Z=199…229mm。

現在の36格子穴について、下面M4ナット用の仮包絡φ8×5mm（Z=224…229）は全位置で公称形状と干渉しなかった。一方、下面からの小型ソケットに相当する仮包絡φ12×40mm（Z=189…229）では、Y=-115と135の各6穴、計12穴がフレーム等に干渉した。残り24穴はこの包絡で干渉しなかった。この工具寸法は購入工具の保証値ではなく、従来の「36穴clear」が工具アクセスを意味しないことを示す設計用検査である。

特にY=135列は溝ナットを使えば活用できるため、穴が無意味という指摘ではない。しかし汎用天板なら、利用方法の揃った中央格子と専用の外周固定穴へ分ける方が説明・組立が簡単になる。中央の汎用穴を|Y|≦100mm程度に収める案は、フレーム端まで20mm以上を残しやすい。ピッチや穴数は搭載例と加工費で選ぶ。

## スイッチ配置の推奨

二つの機能は維持する。主電源を省くと電池の抜き差しが日常操作になり、非常停止でPCを落とす構成にすると停止のたびにLinuxの電源が切れるため、現状の分担は合理的。

二つの箱をそのまま最適とする理由もないが、単純に中央へ一箱化すると電池の後方取り出しを塞ぎやすい。E3の電池本体はY±37.5mm、アダプターはY±45mm、左右のスイッチ箱はそれを避けている。**中央の電池サービス通路を残し、床で支持する条件を先に固定してから箱を整理する**こと。箱の幅・高さだけを小さくするより、主電源の端子向きと非常停止の接点取り外し空間を先に決める。リブとナットを詳細化した後でも別箱が簡単なら、別箱を維持してよい。

IDECのナットはφ28.4×高さ5mmの掲載があり、専用締付工具の外径はφ28mm。ナット2.0N·m、接点の端子ねじは対象線材に応じ1.0～1.3N·mの記載がある。付属の接点レバーストッパも組立工程に含める。蓋に直接文字を印刷すれば、余分な銘板の購入や板厚増を避けられる。[IDECメーカー作成カタログ pp.3–6](https://www.tdcjapan.com/wp-content/uploads/2017/06/P5204A-HW-with-RemovableContactBlock.pdf)

なお、旧日本語カタログの直接開路力50Nと別地域掲載の80Nには差がある。現在の蓋検討荷重150Nは双方より大きいが、販売改訂を照合せず「メーカー荷重の3倍」と断定しない。蓋の梁計算だけで床のナット保持、印刷層方向、繰り返し押下や長期クリープまで検証済みとは扱わない。

## 電装・運用の妥当性と残る条件

amon3214のメーカー表示はDC24V車10A以下、穴φ12、板厚1～4mm、250型メス端子。現在の3mm蓋は板厚条件内である。主電源の約8.14Aという予算はPC30Wなどを仮定した値なので、PC決定後に更新する。[エーモン公式](https://www.amon.jp/products2/detail.php?product_code=3214)

HW1B-V402Rはφ40の押して保持・回して復帰する2NCねじ端子品。個別のモーター電源を同時に開く選定方針は明確である。[IDEC公式](https://www.idec.com/ja-jp/switches-indicator-lights/switches-pushbuttons/emergency-stop-switches/hw-22mm-estop/hw1b-v402r)

M0601C_111の内蔵ブレーキは速度モードでの指令機能であり、電源を切る単純スイッチで「ブレーキしてから遮断」は実現しない。また、取扱説明書の過電流・失速保護には自動復帰が記載されている。初回試験は平坦床・低速のまま、通常停止と電源遮断時の惰走を別に測る。過去の減速度計算値を電源遮断後の実停止距離として使わない。[メーカー説明書 pp.9–13](https://d2air1d4eqhwg2.cloudfront.net/media/files/a48110eb-432c-4083-a159-9e0f35913b23.pdf)

Pico用HATは2つのUART系統を持つ完成基板なので、別のUSB–RS485変換器や裸ICを追加する必要はない。ただし既製HATを挿しただけではUSBとモーター間の転送・停止処理は完成せず、Picoのファームウェアは別の実装作業として残る。[Waveshare公式](https://www.waveshare.com/wiki/Pico-2CH-RS485)

## 今回の修正範囲と改善候補

今回最低限行うのは、R1のスイッチ固定・工具空間・線保持、R4の操作空間と表示、R5/R6の天板配置と使用例、およびR3の復帰仕様の明確化。R2/R7の現物依存項目は未完として残し、購入・製作確定の条件を具体化する。

改善候補は、天板の六角穴付きボルトを低頭品へ置換、工具なし留め具、スイッチ箱統合、既製の非常停止ボックスへの置換。これらは強度・工具・価格の比較を伴うため、自動的には採用しない。機械ブレーキ、産業用安全コントローラー、二重リレー、専用ARMボタンを本レビューから必須追加とはしない。

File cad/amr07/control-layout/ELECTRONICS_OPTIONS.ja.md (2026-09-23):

# 手持ちPicoを使う制御・電源保護の旧比較

**現行はE3：LinuxミニPC → USB → Pico → 2CH RS485基板です。** 後方の2NC非常停止で左右モーター電源を直接遮断する案へ変更し、主電源は残しています。[最新設計](../pico-control/README.ja.md)／[配線構成](../pico-control/WIRING.ja.md)。以下は旧案の履歴で、現行の必須機能や部品表ではありません。

<details>
<summary>旧比較の記録を開く</summary>

**2026-09-23訂正：専用基板を第一候補とした推奨は撤回した。** ユーザーには回路製作設備がなく、こちらも完成した回路図・PCB・ファームウェア・製作見積を用意していない。一般の実装料金を調べただけでは、組み立てられる電装にならない。[現在の製作条件・候補調査](../electrical-buildability/README.ja.md)／[訂正後BOM](../fixed-deck/BOM.ja.md)を参照。

以下は旧比較の履歴。通信・リレーのモジュールだけで保護全体が完成しない点は変わらないが、専用基板の設計・製作や残る配線加工をユーザーへ任せる根拠にはしない。旧裸部品の価格と完成品の費用を混同しない。

Pico本体は所有申告により購入費0円とした。初代／H／W／2などの型番、ピン実装、USB線の所有は未確認。旧Pico Hの920円だけを除外し、基板や配線まで所有とは仮定しない。型番確定後にピン割当・電源入力・ヘッダー高さを決める。

## 同じ役割を比較する

| 方法 | 確認できた費用 | 自分で行う作業 | 配置・制約 |
|---|---:|---|---|
| 部品から専用基板を作り手実装 | 既存RS485 IC70＋リレー2個770＋5V DC/DC850＝**1,690円** | 基板製作、はんだ付け、配線、検査。回路設計も別途必要 | 一体化しやすいが、これは3機能分の部品代だけ |
| 小型モジュールを組み合わせる | AmazonのPico用RS485候補1,900＋リレーキット2枚1,200＋DC/DC850＝**3,950円** | リレーと端子台のはんだ付け、モジュール間配線、保護回路追加 | リレー基板だけで54×30mmを2枚。70×70mm予約枠へ端子余裕込みで収まるか再設計が必要 |
| Pico用8chリレー基板を使う | リレー基板3,476＋RS485候補1,900＋DC/DC850＝**6,226円** | 配線と独立保護回路追加 | 145×90mm・243g。必要なリレー2個に対して大きく、現在の予約枠に入らない |
| 専用基板を製造・実装外注 | **総額未見積**。下記の公式実装料金を確認 | 回路・基板設計、製造データ作成、受入試験、ハーネス組立 | 細かいICを手ではんだ付けする負担を減らせる。設計・検証は依然必要 |

3,950円−1,690円＝2,260円は**通信・リレー・5V電源だけ**の差。保護回路全体の差額ではない。上表はいずれもE-stop、主スイッチ、ARM、独立低電圧保護、回生クランプ、外部WD、端子、ヒューズ、ケース、送料を揃えた完成品価格ではない。

出典：[M78AR05-1・850円](https://akizukidenshi.com/catalog/g/g113536/)、[AE-RELAY953B-5V・600円/キット](https://akizukidenshi.com/catalog/g/g111245/)、[Pico-Relay-B・3,476円](https://www.switch-science.com/products/7546)、[Amazon RS485候補・1,900円](https://www.amazon.co.jp/dp/B0GKHKCZV3)。確認日は2026-09-23。

RS485候補はSP3485・3.3V系の販売表示を確認したが、1,900円の出品をWaveshare正規品と断定しない。[Waveshare公式仕様](https://www.waveshare.com/wiki/Pico-2CH-RS485)は52.5×21mm、Pico用2ch。国内正規販売の[スイッチサイエンス](https://www.switch-science.com/products/7548)は1,287円だが確認時売切れ。同じ2chでも出品者・基板改訂・電源接続を受入確認する。左右モーターを別IDの1本のバスへ接続すれば1chで足りる。

リレーキットはドライバ部実装済みでも、リレー・端子台のはんだ付けが必要。接点のDC負荷・突入適合も確認が必要で、「30A」という商品名だけで既存G5LEの代替にしない。

## 既製モジュールで置換しきれなかった機能

| 機能 | 調べた候補 | 今回の判断 |
|---|---|---|
| 全負荷の低電圧遮断 | [CZH-LABS D-1021V3 18V30A、22 USD](https://czh-labs.com/products/czh-labs-low-voltage-disconnect-module-lvd-18v-30a-protect-prolong-battery-life) | 商品説明では低電圧／復帰とも5秒遅延、自動再投入あり。16.5V遮断・18V復帰可能＋手動ARMという現行要件との一致は未確認 |
| 回生吸収 | [Pololuシャントレギュレータ](https://www.pololu.com/category/249/shunt-regulators) | 短時間パルス用というメーカー条件と、今回の約10J・0.5秒試験が一致しない。固定26.4V型もモータ端24V未満の要件に合わない。単純置換しない |
| 外部監視＋手動再許可 | Pico内蔵WD、一般リレーボード、周期電源タイマーなど | Pico停止時にも遮断し、故障復帰だけでは再投入しない仕組みを、今回確認した安価な1枚で置換できていない |

これらは必要機能が全部存在しないという主張ではなく、今回比較した候補の判定。運転条件と[保護回路案](../ELECTRICAL_AND_VALIDATION.ja.md)を揃えて評価する。非常停止はPicoのソフト処理を待たず、2NC接点で2個のリレーコイルを切る構想を維持する。

## JLCPCBの公式実装料金を使った比較

2026-09-23に確認した[公式料金表](https://jlcpcb.com/help/article/pcb-assembly-price)（2026-09-09更新）のEconomic PCBAを使用する。

| 料金項目 | 公式表示 |
|---|---:|
| セットアップ／注文 | 8.18 USD |
| ステンシル | 1.53 USD |
| SMT実装 | 0.0016 USD/接合点 |
| 手実装 | 0.0164 USD/接合点 |
| 手はんだ作業の固定費（発生時） | 3.58 USD/注文 |
| Extended部品のフィーダー | 3.07 USD/種類 |
| 任意の配置確認 | 0.45 USD |

基板代、部品代、送料、税、為替手数料は別。複数設計の面付けをしないのに8.21 USDの面付け料を必ず足す、といった計算はしない。最低実装数量は[公式能力表](https://jlcpcb.com/capabilities/pcb-assembly-capabilities)で2枚。注文単位の固定費を1台分へ按分して、支払額と混同しない。

記録済み参考為替157.2672円/USD（2026-09-21）なら、セットアップ＋ステンシル＋手はんだ固定費は13.29 USD≒2,090円。Extended部品が5種類なら、この部分は28.64 USD≒4,504円、10種類なら43.99 USD≒6,918円になる。**これは料金表の感度計算で、AMR用基板の実見積ではない。** Gerber・製造BOM・CPLが未作成なので、製造サイトへ設計データを投入した完成価格は取得していない。基板設計後に数量・部品在庫・送料を揃え、実際の見積で決める。

## CADとBOMへの反映範囲

後方E-stop、手動ARM、主スイッチは型式・取付ケース・固定位置をCADへ反映済み。前方1階にある70×70×35mmの保護回路枠と、70×45×30mmのPico／通信枠は、**回路基板の完成形ではなく予約容積**。商品未確定の計算機、実装基板、端子配線は未計上として残す。

旧制御・保護候補は、USB線500円を含め**8,475円**（Pico0、E-stop3,153、主電源621、ARM835等）。旧後方ケース用座金968円を同カテゴリに含めた表示は9,443円だった。どちらも完成電装費ではない。E1で専用回路部品3,366円とはんだ端子E-stop3,153円を購入表から外した。残る1,956円は主電源・ARM・USB線だけで、代替電装費は未計上。座金はD6.9の共通締結材へ整理済みで、この旧金額を現行費用へ加算しない。

</details>

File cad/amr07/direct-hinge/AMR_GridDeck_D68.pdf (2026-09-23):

# AMR_GridDeck_D68 / D6.8 / QUOTATION ONLY

2026-09-23 | mm | Quantity 1 | Matching STEP required | Not released for fabrication

300 x 300; thickness4 +/-0.10

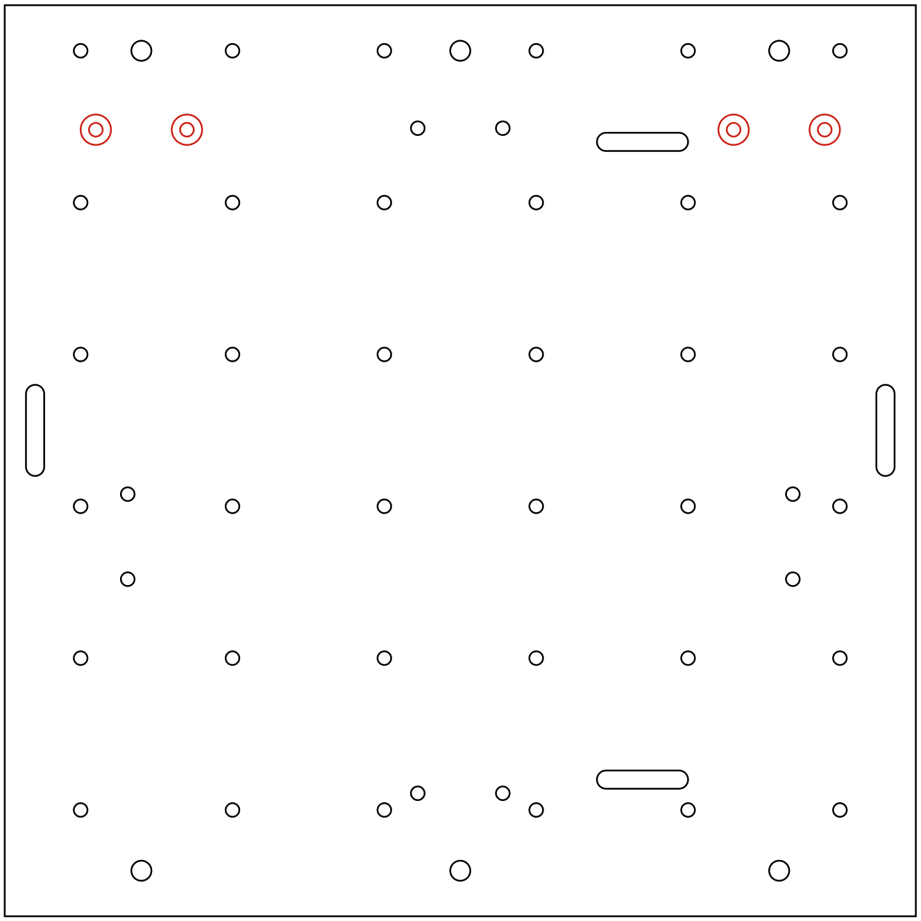
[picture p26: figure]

TOP / Origin centre(0,0); red rings mark4 new holes (rings are NOT machined).

SIDE:4 +/-0.10. Flatness<=0.5 over300. Preserve flatness during shipment.

Aluminum 6061-T6; require Rp0.2 >=240MPa.
As machined. No blasting, anodizing or cosmetic finish. No threads or inserts. All specified holes are THROUGH. Deburr both sides. Edge break <=0.2mm.
Hole coordinates +/-0.10mm; D4.5 +0.2/0.
Other dimensions ISO2768-m unless specified.
Do not change dimensions, material, R or holes without review. STEP SHA256:
f00304de17c088257c92abcfd596f50c 49d6a75395b6023d93de5facbf8d38f8

36 GRID D4.5: Cartesian product of X=-125,-75,-25,25,75,125; Y=-115,-65,-15,35,85,135. 6 FRAME D6.6 +0.2/0: X=-105,0,105; Y=+/-135.
8 STOP D4.5: X=+/-109.5,Y=-39,-11;
and X=+/-14,Y=+/-109.5.
4 NEW HINGE D4.5: X=-120,-90,90,120; Y=109.
4 slots30x6 R3: (+/-140,10) alongY;
(60,+/-105) alongX. Length30+/-0.2,width6+0.2/0.
Same D3 plate outline/grid, with ONLY4 new plain holes. Keep holes separate; no tapping; quantity1.

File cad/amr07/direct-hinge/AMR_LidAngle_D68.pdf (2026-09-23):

# AMR_LidAngle_D68 / D6.8 / QUOTATION ONLY

2026-09-23 | mm | Quantity 2 | Matching STEP required | Not released for fabrication

SIDE Y-Z:50 x22; foot/upright4 +/-0.10; inside root R3.

TOP X-Y:50x50, width50; two base holes, no threads.

Aluminum 6061-T6; require Rp0.2 >=240MPa.
As machined. No blasting, anodizing or cosmetic finish. No threads or inserts. All specified holes are THROUGH. Deburr both sides. Edge break <=0.2mm.
Hole coordinates +/-0.10mm; D4.5 +0.2/0.
Other dimensions ISO2768-m unless specified.
Do not change dimensions, material, R or holes without review. STEP SHA256:
b4b467c1241a4a0eb4f270e089accf9c a11f9a31a81cd5eae1309d6e43b7a40a

One identical part; quantity2, not mirrored. Overall50(X) x50(Y) x22(Z). Main walls4 +/-0.10. One inside root R3; other outline per STEP.
4x D4.5 +0.2/0 THROUGH:
2 base bores: X=+/-15,Y=9,axisZ.
2 upright bores: X=+/-15,Z=13,axisY.
Hole centre coords +/-0.10 from exported local origin. Main mounting faces perpendicular0.2/22.
Main foot and upright seating flatness0.15.
No opening stops, ears or additional flanges.
50mm foot preserves existing cargo belt clearance. Schematic sharp lines atR3; STEP controls actual radii. Manual review of machining access/R3 is required.

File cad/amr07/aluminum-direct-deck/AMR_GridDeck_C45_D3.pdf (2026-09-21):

# AMR_GridDeck_C45_D3 - GRID DECK / QUOTATION ONLY

Revision D3 | 2026-09-22 | All dimensions in mm | Quantity 1 | Not released for fabrication or loaded use

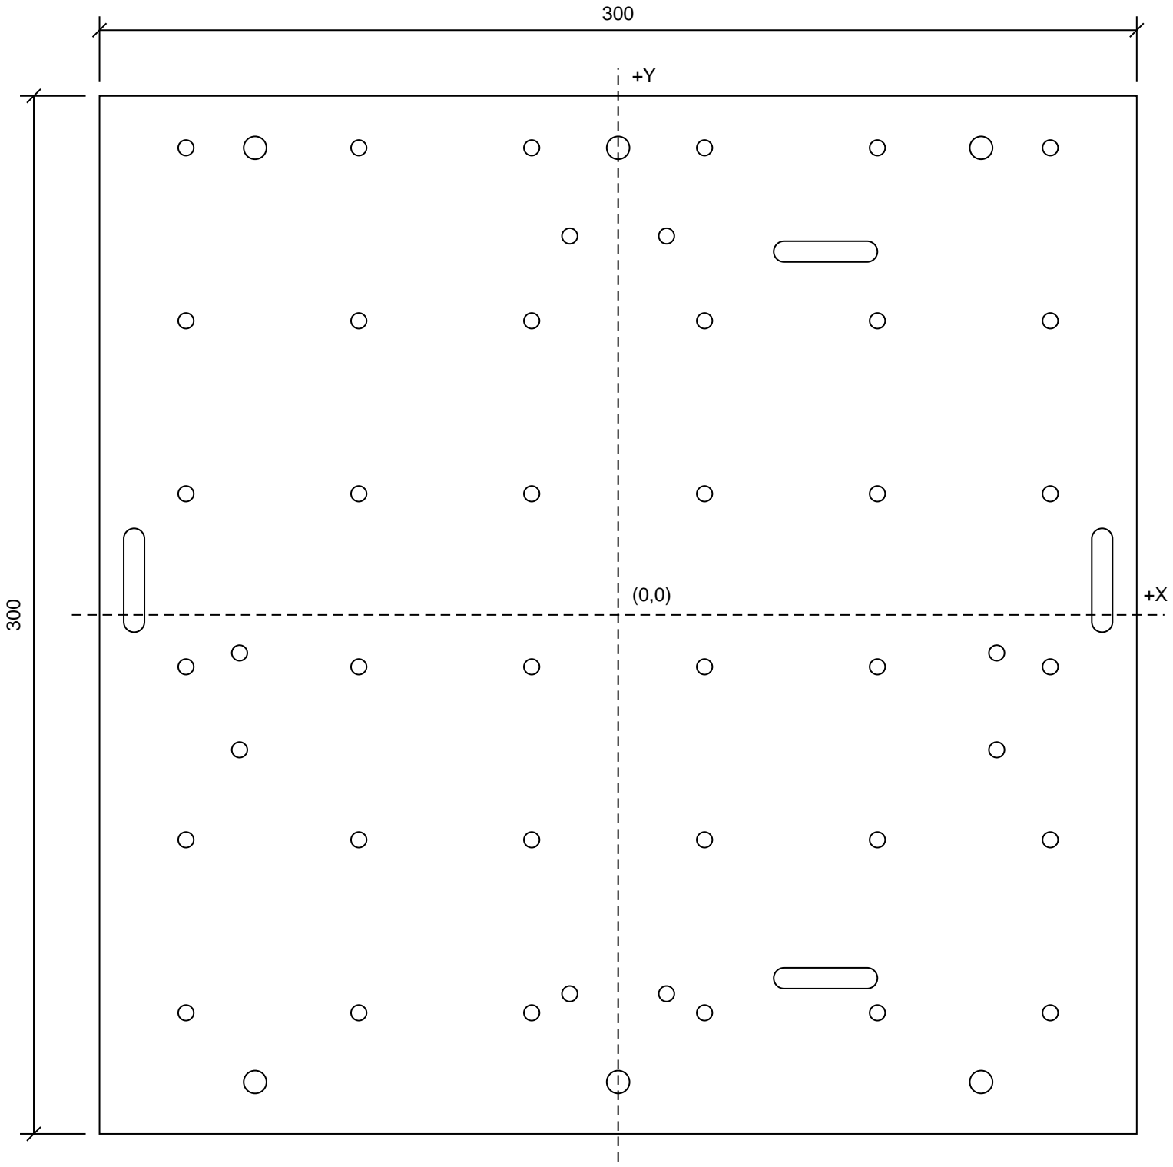
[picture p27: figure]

TOP VIEW | Origin at plate centre | 50mm pitch; X edge25, Y first35 / last15 (grid Y offset+10)
SIDE VIEW | Thickness 4 +/-0.10 | All holes/slots through

MATERIAL / FINISH
Aluminum 6061-T6 (JLCCNC Aluminum 6061 selection). Require Rp0.2 >=240 MPa; confirm material lot / temper. As machined; no blasting, anodizing or cosmetic finish.
No assembly or inserts. Remove burrs on both faces. Edge break <=0.2; preserve nominal hole/slot sizes. Plate flatness <=0.5 over 300. Protect flatness in shipment.

HOLE SCHEDULE - ALL CENTRES FROM (0,0)
GRID: 36 locations, full Cartesian product of:
X = -125, -75, -25, 25, 75, 125
Y = -115, -65, -15, 35, 85, 135
36 x D4.5 +0.2/0 THROUGH. NO THREADS.

FRAME: 6 x D6.6 +0.2/0 THROUGH
X = -105, 0, 105; Y = -135, 135 (all combinations)

STOPS: 8 x D4.5 +0.2/0 THROUGH, unthreaded X=+/-109.5, Y=-39,-11; and X=+/-14, Y=+/-109.5

STRAPS: 4 x obround slots 30 overall x 6 wide, R3 Centres (+/-140,10), axis Y; (60,+/-105), axis X

TOLERANCES / MODEL PRIORITY
Hole and slot centre coordinates +/-0.10 from origin.
Slot width 6 +0.2/0; length 30 +/-0.2.
Other linear/angular dimensions: ISO 2768-m.
PDF controls threads and tolerances; STEP controls outline. Do not merge holes or alter geometry without review.

QUOTE SCOPE
Includes material, all 50 round holes and all 4 strap slots. No mounting hardware. Ship quote to Japan separately. D3: direct on3030. No support parts or spacers included.

Matching STEP: AMR_GridDeck_C45_D3.step
STEP SHA256: c38862f7ac33c2f30bba198fce54ff1bcb22bd75820bd994dd8b4a5e7f5c0d4c | Sheet 1 / 1 | Drawing generated from geometry.json

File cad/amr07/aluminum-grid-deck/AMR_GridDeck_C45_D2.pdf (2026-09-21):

# AMR_GridDeck_C45_D2 - GRID DECK / QUOTATION ONLY

Revision D2 | 2026-09-22 | All dimensions in mm | Quantity 1 | Not released for fabrication or loaded use


TOP VIEW | Origin at plate centre | Grid edge offset 25, pitch 50 (both axes)
SIDE VIEW | Thickness 4 +/-0.10 | All holes/slots through

MATERIAL / FINISH
Aluminum 6061-T6 (JLCCNC Aluminum 6061 selection). Require Rp0.2 >=240 MPa; confirm material lot / temper. As machined; no blasting, anodizing or cosmetic finish.
No assembly or inserts. Remove burrs on both faces. Edge break <=0.2; preserve nominal hole/slot sizes. Plate flatness <=0.5 over 300. Protect flatness in shipment.

HOLE SCHEDULE - ALL CENTRES FROM (0,0)
GRID: 36 locations, full Cartesian product of:
X = -125, -75, -25, 25, 75, 125
Y = -125, -75, -25, 25, 75, 125
36 x D4.5 +0.2/0 THROUGH. NO THREADS.

FRAME: 6 x D6.6 +0.2/0 THROUGH
X = -105, 0, 105; Y = -135, 135 (all combinations)

STOPS: 8 x D4.5 +0.2/0 THROUGH, unthreaded (X,Y) = (+/-109.5, +/-19) and (+/-19, +/-109.5)

STRAPS: 4 x obround slots 30 overall x 6 wide, R3 Centres (+/-120,0), long axis Y; (0,+/-120), long axis X

TOLERANCES / MODEL PRIORITY
Hole and slot centre coordinates +/-0.10 from origin.
Slot width 6 +0.2/0; length 30 +/-0.2.
Other linear/angular dimensions: ISO 2768-m.
PDF controls threads and tolerances; STEP controls outline. Do not merge holes or alter geometry without review.

QUOTE SCOPE
Includes material, all 50 round holes and all 4 strap slots. No mounting hardware. Ship quote to Japan separately. D2: six discrete metal supports. No support parts included.

Matching STEP: AMR_GridDeck_C45_D2.step
STEP SHA256: 60c1442cde55d90bfcd4b6b8cbafcdc4a3560e4c4d35523c417fd08a4043051e | Sheet 1 / 1 | Drawing generated from geometry.json

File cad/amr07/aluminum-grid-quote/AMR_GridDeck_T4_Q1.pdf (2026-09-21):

# AMR_GridDeck_T4_Q1 - GRID DECK / QUOTATION ONLY

Revision Q1 | 2026-09-21 | All dimensions in mm | Quantity 1 | Not released for fabrication or loaded use


TOP VIEW | Origin at plate centre | Grid edge offset 25, pitch 50 (both axes)
SIDE VIEW | Thickness 4 +/-0.10 | All holes/slots through

MATERIAL / FINISH
Aluminum 6061-T6 (JLCCNC Aluminum 6061 selection). As machined; no blasting, anodizing or cosmetic finish.
No assembly or inserts. Remove burrs on both faces. Edge break <=0.2; no large chamfers on M4 threads. Plate flatness <=0.5 over 300. Protect flatness in shipment.

HOLE SCHEDULE - ALL CENTRES FROM (0,0)
GRID: 36 locations, full Cartesian product of:
X = -125, -75, -25, 25, 75, 125
Y = -125, -75, -25, 25, 75, 125
36 x M4x0.7-6H THROUGH, full available depth.
STEP shows D3.3 pilot bores; finished threads per PDF. Thread all 36 grid bores. Remaining 14 holes unthreaded.

FRAME: 6 x D6.6 +0.2/0 THROUGH
X = -120, 0, 120; Y = -135, 135 (all combinations)

STOPS: 8 x D4.5 +0.2/0 THROUGH, unthreaded (X,Y) = (+/-109.5, +/-19) and (+/-19, +/-109.5)

STRAPS: 4 x obround slots 30 overall x 6 wide, R3 Centres (+/-120,0), long axis Y; (0,+/-120), long axis X

TOLERANCES / MODEL PRIORITY
Hole and slot centre coordinates +/-0.10 from origin.
Slot width 6 +0.2/0; length 30 +/-0.2.
Other linear/angular dimensions: ISO 2768-m.
PDF controls threads and tolerances; STEP controls outline. Do not merge holes or alter geometry without review.

QUOTE SCOPE
Includes material, all 50 round holes and all 4 strap slots.
No mounting hardware. Ship quote to Japan separately. Quote candidate only: accessory clearance / strength pending.

Matching STEP: AMR_GridDeck_T4_Q1.step
STEP SHA256: 8d79d37fda7591f84ca79d677785913bda73e97ba0a26710acb1f9097eee2874 | Sheet 1 / 1 | Drawing generated from geometry.json

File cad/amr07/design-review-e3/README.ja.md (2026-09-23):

# E3レビューとE4での対応

ユーザー依頼により、機構設計とロボット/電装の独立AI担当へレビューを依頼し、両報告を受領後にE4を作成した。人間専門家への外部発注や認証ではない。

- [機構設計レビュー](MECHANICAL_REVIEW.ja.md)
- [ロボット・電装レビュー](ROBOTICS_REVIEW.ja.md)
- [変更天板の強度・締結再レビュー](DECK_REVISION_CHECK.ja.md)
- [E4の再確認](ROBOTICS_RECHECK.ja.md)
- [修正版E4](../reviewed-design/README.ja.md)

| 指摘 | 対応 | 状態 |
|---|---|---|
| M-01/R1：ナット・工具・配線保持 | ナットと端末確保空間を追加、主電源リブ逃げ/補強環、箱内結束橋、電池を外す組立手順 | 公称CAD対応。主電源実寸・端末・配線は未確定 |
| M-02/R6：突出した固定部と常設ストッパ | 外周6点へ移動、頭高さ1.5mm、ストッパは標準撤去。250角の荷物例を確認 | CAD対応。低頭ねじの実締付・実荷重試験は未実施 |
| M-03/R5：穴の非対称/裏工具制約 | 中央原点50mmピッチ25穴、全穴同じ貫通締結。長穴対称化 | 電池外しで全25穴工具クリア。装着時3穴制約を明記 |
| R4：操作空間 | 上からの押下/解除と後ろからの接近を確認、表示を指定 | CAD包絡確認。実機操作性は未確認 |
| M-04：PLA締付クリープ | 押下と持続締付を分離し、試験条件/未確認を明記 | 未解消、実印刷試験が必要 |
| R2：電装負荷適合 | NC各1モーターを維持、実突入/最細線/ヒューズを確認項目化 | 未解消、通電前の条件 |
| R3：停止後の復帰 | 古い指令破棄、片輪異常で両輪禁止、ゼロ再接続と明示RUNを仕様追加 | FW未実装・未試験。短断電の検出保証なし |
| R7：完成ハーネス | 各系統の既製品/端末加工調達方針を表にした | 型式・線径・端末・長さの確定が残る |
| 新形状の加工価格 | 旧天板見積を現行BOMから除外 | 新STEPの実再見積待ち |

標準にモニター・産業用安全コントローラー・二重リレー・専用ARMを追加しない。スイッチ箱統合は電池サービス口を塞ぐため採用しない。皿M6は板の残肉と追加加工を避け、極低頭品を選んだ。

寸法照合の追補：公開済みの3214外形とHW取付図を再照合し、仮円柱・接点包絡・回り止めを訂正。[根拠と未確定項目の分類](../reviewed-design/SWITCH-DIMENSIONS.ja.md)。元のレビュー報告は受領時の記録として保持する。

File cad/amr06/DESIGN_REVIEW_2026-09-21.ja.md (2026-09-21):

# AMR設計レビュー：要求・固定部・駆動・製造

2026-09-21。対象コミット：`0c7188a1a10d372b0be04ea4c2f06cda349cd7f0`。対象はA4の価格基準とD5の比較CAD。要求・荷台・重量、支持・締結・公差、駆動・電装の3担当で読み取りレビューを行い、根拠を突き合わせた。

**判定：PLAによる形状の仮合わせを進める資料はある。15kg積載走行を成立させる設計としては、要求と機能公差・荷重支持・停止方式を詰める必要がある。** 今回はレビューを完了したもので、指摘項目を修正済みとするものではない。CAD、見積済みSTEP/PDF、計算入力は変更していない。

## 使用したレビュー手順と見つかったスキル

| スキル | 確認した内容 | 今回の扱い |
|---|---|---|
| [mechanical-design-review](https://github.com/aa15107688191-collab/codex-mechanical-engineering-skills/blob/df43f1c8f33032bcaa1a7fd6653e199b1c452df4/skills/mechanical-design-review/SKILL.md) | 第三者公開・MIT。要求、荷重経路、締結、公差、加工・組立・保守、重要度、検証計画を整理する手順書 | SKILL.md全文を読み、今回のレビュー手順として使用。解析機能の実行やローカルへの新規インストールはしていない |
| [Mechanical AI Skill](https://github.com/almightyshui/Mechanical-AI-Skill/blob/f15480dc5a50f3c583cb43965dc99ad944ee6f2c/SKILL.md) | STEP/CADの理解・干渉・基本解析などの連携を案内。接触・非線形・自動設計レビュー等はProfessionalの範囲と記載 | ソースの説明を確認した候補。実行・精度・この環境での動作は未検証。今回は既存FreeCAD検査と計算を使用 |
| [cnc-quote](../../skills/cnc-quote/SKILL.md) | このプロジェクトの実STEP・寸法図を加工サイトへ投入し、条件と価格の証拠を残す | 既存の見積根拠をレビュー。形状や公差を変更した後の再見積に使う |

手元のスキルとOpenAI公開カタログを検索した範囲では、機械設計レビュー専用の導入済みスキルは見つからなかった。上の外部手順書が今回の用途に合う。参照した手順書のSHA-256は `57a34bb2664caf9f790115fee20e11bc60b495e9eac3679aab0818cda73a4956`。

以下のP1は製作用の条件確定または積載走行の判定前に解消すべき項目、P2は詳細設計・採用品確認・運用検証で解消すべき項目を示す。「未検証」は故障確定を意味しない。最終的な製作・使用の判断は、責任を持つ設計者が計算と実物の検証結果を確認して行う。

## 指摘事項

### DR-01 / P1：隙間計算の円弧公差が見積図面に指定されていない

**確認済みの条件不一致。** [requirements.json](requirements.json)の137〜138行は主円弧R9.7に±0.05mmを仮定している。一方、実際に提出した[D5図面PDFの2頁](candidates/M0601C_mount_D5_Compact_R2.pdf#page=2)は、特別公差を受け平面8.25±0.05mmだけに限定し、Rや穴位置への追加指定はしていない。[図面生成元](make_quote_drawings.py)271〜285行とも一致する。

したがって、[強度レビュー](STRENGTH_REVIEW.ja.md)158行の円弧隙間0.125〜0.325mmは計算入力に対する値であり、この見積条件で製造される部品の保証範囲として使えない。φ2.8・PCD15.2の3穴も、受け軸との位置関係や座面の幾何公差が未確定である。公称CADで組み付くことだけでは、実部品の同時組付けと座面接触を保証できない。

**解消条件：** 実モーターの固定端と孔群を基準に、必要な受け輪郭・穴位置・座面の平面度と直角度・背肉の公差を定め、最悪寸法の組合せで全輪郭と3本のねじが成立することを確認する。計算入力、製作図、受入測定項目を一致させる。公差変更後は新しい図面版で加工費を再見積し、現在の価格を流用しない。

### DR-02 / P1：受けと小ねじの荷重分担が未確定で、安全率2を判定できない

**要求を満たす証拠が不足。** φ2.8孔とM2.5ねじの公称片側逃げは0.15mm、受けの公称隙間は主円弧0.20mm・平面0.25mm。端面摩擦が切れて相対移動する場合、方向と実寸法によっては、受けが支持する前に小ねじ軸と孔縁が接触する組合せも考えられる。受け深さ9mmだけで小ねじが保護されるとは判断できない。

受け・摩擦の分担をゼロとした感度計算では、片輪245N・トルク0.96N·m・横力ゼロでM2.5一本の最大せん断約121N、引張方向成分約445Nが現れる。これは実際のボルト力の予測ではなく、分担を未確定のままにする影響を示す比較である。母材、ねじ等級、締付条件、局所座面は未確認。[荷重経路・数値・未確認事項](STRENGTH_REVIEW.ja.md)、[計算入力](requirements.json)

**解消条件：** DR-01の公差設計と一体で、受け・端面摩擦・小ねじの荷重分担を決める。締付予圧、母材のねじ山、局所座面、根元と孔の応力、3030側接合まで評価し、定めた荷重条件に対する安全率2を示す。剛性は別の変位基準で判定し、未合意の0.1mmを既定の合格値としない。

### DR-03 / P1：15kg用の荷台と荷物固定が未設計・未計上

**未設計であることは確認済み。重量超過や破損の確定ではない。** A4の6.79kgは機械4.69kg＋電装の重量枠2.10kg。D5の6.74kgも同じ範囲で、15kg荷台は含まない。現行PLAトレイは電装・電池用であり、15kg荷台の支持構造へ読み替えられない。[A4重量集計](../amr05/validation_results.json)、[D5集計範囲](assembly_validation.json)、[現在の検討範囲](README.ja.md)

**解消条件：** 荷台の寸法・材料・支持点・荷物固定と重心範囲を決め、荷台→3030→車輪/キャスターへの荷重経路を計算する。荷台、固定部、追加カバー・電装を含めて車体10kg以下と重心位置を再集計する。A4の残り約3.21kgは未確定部品の追加・変更を受け持つ余地であり、荷台へ全量使える確定余裕ではない。

### DR-04 / P1：総25kgと従来の5°登坂・駆動余裕1.5が同時には成立しない

**記載された計算条件では不適合を確認。運用要求の確定は別途必要。** 総25kg、5°、加速度0.2m/s²、転がり抵抗係数0.03では必要0.8483N·m/輪。余裕1.5を含めると1.2724N·mとなり、公表定格0.96N·mを超える。「5°で必ず動かない」という判定ではなく、要求した余裕を確保できないという結果である。[駆動計算](STRENGTH_REVIEW.ja.md)、[メーカー仕様](https://shop.directdrive.com/pages/m0601c-111-specs)

**解消条件：** 積載量、車体重量、勾配、加減速、床、連続時間を一つの運用条件へ揃えて再判定する。既定モーターを維持する場合は、そのモーターで成立する条件を明示して決める。拘束トルク2N·mを連続性能に使ったり、未合意の平地限定に置き換えたりして解消済みとしない。
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

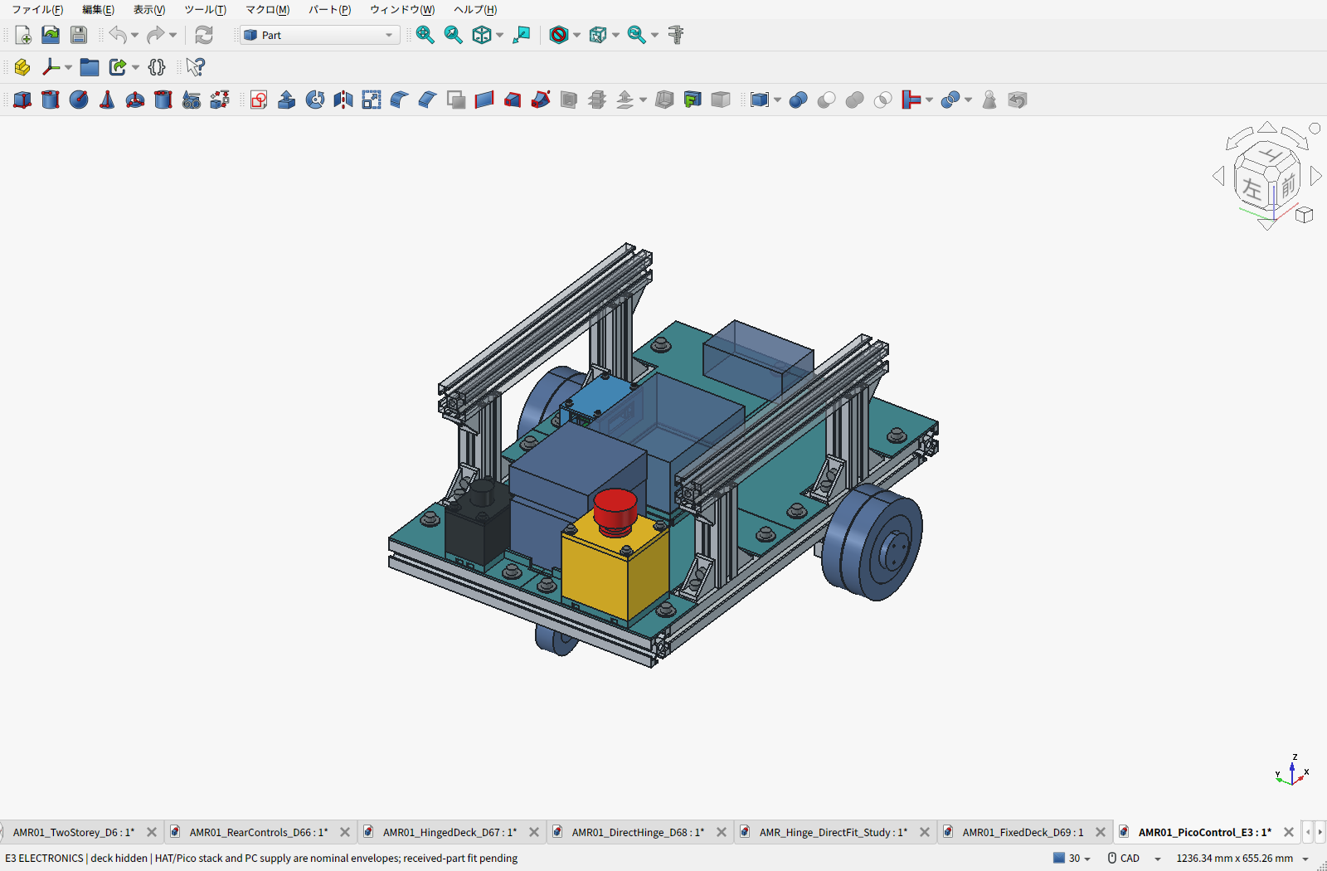
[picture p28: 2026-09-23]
cad/amr07/pico-control/cad-screen-electronics.png

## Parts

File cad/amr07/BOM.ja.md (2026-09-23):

# A6 BOM — 平地10kg・追加機械ブレーキなし

> **現行D6.5 BOM：[Markdown概要](two-story/BOM.ja.md)／[全明細Markdown](two-story/BOM-details.ja.md)／[CSV](two-story/BOM.csv)**。スマートフォンでも型番・購入単位・価格根拠・備考を確認できます。以下とこの階層のCSV・Excelは旧構成の履歴。

> **2026-09-22：DECK_square_barは加工負担のため不採用。** このBOMと添付CSV・Excelの金額・数量は変更前のD2 CADに対する履歴。現行D6の数量・購入数は上のリンク先を参照する。角棒をこの表どおり購入しない。[製作条件](requirements.json)

2026-09-22更新。**途中小計50,468円＋120.90 USD＋未確定分**。キャスターをAmazon273円＋既存Prime会員条件の送料0円で計上した条件付き金額です。車体の完成価格ではありません。購入・材料消費・仮枠を含み、通貨を換算せず集計しています。

[Excel](BOM.xlsx) / [購入一覧CSV](BOM.csv) / [締結部品CSV](fasteners.csv) / [製作品CSV](manufactured_parts.csv)

CADの物理形状298点を各費用行へ照合しました。完成キャスターやタイヤキットは、CAD形状数ではなく完成品の購入数で計上します。電装の半透明予約形状は購入品に数えていません。

フレーム300mmは2本使用・4本組1セット購入。溝ナットは合計50個＝接合セット付属16個＋別購入34個です。未確定の販売パックを架空の「1セット」として確定していません。

小径座金は10枚以上の単価29円が**税別**だったため、10枚税込319円へ訂正しました。旧小計との差は29円です。10枚は数量割引の選択で、最小注文数ではありません。[WILCOの価格表](https://wilco.jp/products/F/FW-EB.html)

タイヤ・キャスター・座金・タイヤ送料条件を今回再確認しました。フレームのAmazon価格は再取得できず、既存価格を参考値として引き継いでいます。その他の価格も全行再調査ではなく、既存調査・見積・仮枠です。[確認記録](bom_price_checks.json)

キャスターは取付寸法を照合したTRUSCO TYG-50に変更し、Amazon.co.jp販売・発送273円＋既存Prime会員条件の送料0円を第一候補とします。直前の498円から225円減。会員ログイン後の最終注文額は未確認。コーナン店舗受取283円＋送料0円も代替経路として確認しました。[購入経路と条件](CASTER_PROCUREMENT.ja.md)。[D2格子穴アルミ板の実見積](aluminum-grid-deck/README.ja.md)を採用し、旧板素材4521円を置換しました。PLA小物の締結材800円は販売価格未確認の予算枠です。

参考円換算は約69,480円＋未確定分（ECB2026-09-21の1USD＝157.2671889円）。決済レート・税・手数料は別です。

## 分類別小計

| 分類 | 円 | USD |
| --- | --- | --- |
| フレーム | 6,659円 | 0.00 USD |
| 駆動・支持 | 24,413円 | 75.02 USD |
| 荷台 | 4,093円 | 28.67 USD |
| 電池・PLA | 1,100円 | 0.00 USD |
| 締結材 | 3,419円 | 0.00 USD |
| 電装候補 | 8,084円 | 0.00 USD |
| 送料 | 2,700円 | 17.21 USD |

金額空欄・未見積の項目は小計に含みません。未選定品は末尾にまとめています。各行の購入予定は実発注・在庫確保を意味しません。

## フレーム

| ID | 品名・仕様 | 使用数 | 購入予定単位 | 明細金額 | 価格根拠 | 購入先・仕様 |
| --- | --- | --- | --- | --- | --- | --- |
| F01 | 3030フレーム 400mm<br>MISUMI NFSL6-3030-400 | 4本 | 4本組×1 | 1,952円 | 過去価格の引継ぎ | [参照](https://www.amazon.co.jp/dp/B0DKF2CCW3) |
| F02 | 3030フレーム 300mm<br>MISUMI NFSL6-3030-300 | 2本 | 4本組×1 | 1,467円 | 過去価格の引継ぎ | [参照](https://www.amazon.co.jp/dp/B0DKDZ8G9G) |
| F03 | 純正接合ブラケットセット<br>HBLFSN6-SET：本体＋CBM6-12×2＋HNTT6-6×2 | 8組 | 1組×8 | 1,540円 | カタログ参考 | [参照](https://jp.misumi-ec.com/vona2/detail/110300442340/) |
| F04 | 追加溝ナット・基礎部分<br>HNTT6-6 | 28個 | 販売単位未確認・必要28個 | 1,200円 | 予算枠 | [参照](https://jp.misumi-ec.com/vona2/detail/110302610850/) |
| P03 | ガセット用アルミ板素材<br>A5052 t3、150×150mm相当 | 1枚 | 素材販売寸法・パック未確定 | 500円 | 予算枠 | 未確定 |

HBLFSN6-SET/HNTT6-6のリンクは仕様参照です。個人購入できる販売経路・販売単位・着荷額はまだ確定していません。

## 駆動・支持

| ID | 品名・仕様 | 使用数 | 購入予定単位 | 明細金額 | 価格根拠 | 購入先・仕様 |
| --- | --- | --- | --- | --- | --- | --- |
| C01 | 自在キャスター<br>TRUSCO TYG-50、径50・取付高65mm、穴ピッチ46×35 | 1個 | 1個×1 | 273円 | 販売表示・条件付き | [参照](https://www.amazon.co.jp/dp/B0795CNFLR) |
| P01 | キャスター取付板の素材<br>A5052 t4、完成寸法80×170mm | 1枚 | 切出し素材の販売単位未確定 | 900円 | 予算枠 | 未確定 |
| D01 | ダイレクトドライブモーター<br>M0601C_111、ドライバ・エンコーダ内蔵 | 2個 | 本体1個×2（想定） | 14,000円 | ユーザー仮枠 | 未確定 |
| D02 | タイヤ・カバーキット<br>DDT-M0601C-TIRE、φ100.7×43mm | 2キット | 1キット×2 | 9,240円 | 販売表示・条件付き | [参照](https://www.switch-science.com/products/9203) |
| Q01 | A6-R1専用モーター金具<br>A6061-T6、90×30×34mm、左右同形 | 2個 | 同形2個で1ロット | 75.02 USD | 実サイト自動見積 | [参照](https://jlccnc.com/jp/cnc-machining-quote) |

## 荷台

| ID | 品名・仕様 | 使用数 | 購入予定単位 | 明細金額 | 価格根拠 | 購入先・仕様 |
| --- | --- | --- | --- | --- | --- | --- |
| DECK_square_bar | 荷台支持・ストッパ用アルミ角棒<br>光 AS6151、15×15×995mm | 1本 | 定尺995mm×1 | 1,507円 | 販売表示・条件付き | [参照](https://store.shopping.yahoo.co.jp/akibaoo/4977720061511.html) |
| DECK_cargo_straps | 荷物固定ベルト<br>E-Value BT-2520BK、25mm×2m | 2本 | 1本×2 | 786円 | 販売表示・条件付き | [参照](https://store.shopping.yahoo.co.jp/hcbrico/4977292226752.html) |
| DECK_plate | 格子穴アルミ荷台 D2<br>6061-T6 300×300×4、36×φ4.5格子、14取付穴、4長穴 | 1枚 | 1枚×1 | 28.67 USD | 実サイト自動見積 | [参照](https://jlccnc.com/jp/cnc-machining-quote) |
| DECK_fasteners_and_extra_slotnuts | 荷台締結材一式<br>M6×30×6、M6座金×12、HNTT6-6×6、M4×25/座金/ナット各8 | 1式 | 個別パック未確定 | 1,500円 | 予算枠 | 未確定 |
| DECK_edge_protection_and_slack_retention | ベルト接触部の保護材・余長固定<br>パッド／エッジ保護／結束部材 | 1式 | 未選定 | 300円 | 予算枠 | 未確定 |

## 電池・PLA

| ID | 品名・仕様 | 使用数 | 購入予定単位 | 明細金額 | 価格根拠 | 購入先・仕様 |
| --- | --- | --- | --- | --- | --- | --- |
| P04 | 電池クレードル・電装トレイ・小型固定具用PLA<br>手持ちPLAの消費量300g仮枠 | 300g | 手持ち材料から消費／購入0 | 600円 | 予算枠 | 未確定 |
| H02 | 電池固定ストラップ<br>型式・幅・長さ未選定 | 2本 | 必要2本、販売単位未確定 | 500円 | 予算枠 | 未確定 |

PLAは手持ち材料300gを使う仮定で、600円は消費材料の評価額です。新規スプール代ではありません。電池本体・充電器は未選定表にあります。

## 締結材

| ID | 品名・仕様 | 使用数 | 購入予定単位 | 明細金額 | 価格根拠 | 購入先・仕様 |
| --- | --- | --- | --- | --- | --- | --- |
| H01 | 基礎部の追加ねじ・ナット・座金<br>詳細は締結部品表、追加66点 | 1式 | 個別パック未確定 | 2,300円 | 予算枠 | 未確定 |
| FIXTURE_HARDWARE | PLA小物の締結材・結束材<br>M4x16×8、通常座金40、大径座金8、M4ナット8、M3ナット4、2.5mm結束バンド2 | 1式 | 販売パック未確定 | 800円 | 予算枠 | 未確定 |
| MW | モーター座面用小径平座金<br>WILCO FW-2505-05EB、2.7×5×0.5mm | 6枚 | 10枚一括購入（数量割引） | 319円 | 販売表示・条件付き | [参照](https://wilco.jp/products/F/FW-EB.html) |

## 電装候補

| ID | 品名・仕様 | 使用数 | 購入予定単位 | 明細金額 | 価格根拠 | 購入先・仕様 |
| --- | --- | --- | --- | --- | --- | --- |
| E02 | Pico接続用USBデータケーブル<br>Pico H側micro-B、ホスト側端子・長さ未定 | 1本 | 必要1本、商品未選定 | 500円 | 予算枠 | 未確定 |
| ELEC_S1 | 非常停止スイッチ<br>IDEC XA1E-BV302R／2NC、φ16.2mm取付 | 1個 | 1個×1 | 3,298円 | 販売表示・条件付き | [参照](https://www.monotaro.com/p/6051/3817/) |
| ELEC_K1_K2 | 駆動電源遮断リレー<br>Omron G5LE-1 DC5／DC5Vコイル、NO接点を2個直列 | 2個 | 1個×2 | 770円 | 販売表示・条件付き | [参照](https://jp.rs-online.com/web/p/power-relays/0369466) |
| ELEC_U1 | モーター制御・監視マイコン<br>Raspberry Pi Pico H SC0917／Pico H、RS485の唯一のマスタ | 1個 | 1個×1 | 920円 | 販売表示・条件付き | [参照](https://akizukidenshi.com/catalog/g/g118085/) |
| ELEC_U2 | 外部ウォッチドッグIC<br>CD74HC123E／再トリガ型ハートビート監視 | 1個 | 1個×1 | 140円 | 販売表示・条件付き | [参照](https://eleshop.jp/shop/g/gT11488/) |
| ELEC_U3 | 手動再始動ラッチIC<br>TC74HC74AP／ARM押下エッジで許可 | 1個 | 1個×1 | 33円 | 販売表示・条件付き | [参照](https://eleshop.jp/shop/g/gT11476/) |
| ELEC_PS1 | 監視回路用DC/DC<br>M78AR05-1／5V 1A、主計算機用とは別 | 1個 | 1個×1 | 850円 | 販売表示・条件付き | [参照](https://akizukidenshi.com/catalog/g/g113536/) |
| ELEC_U4 | RS485トランシーバIC<br>MAX3485ED (HTC)／3.3V、IC単体 | 1個 | 1個×1 | 70円 | 販売表示・条件付き | [参照](https://akizukidenshi.com/catalog/g/g116211/) |
| ELEC_RDUMP | 回生吸収抵抗<br>ARCOL HS50 22R J／22Ω 50W、放熱条件付き | 1個 | 1個×1 | 1,033円 | 販売表示・条件付き | [参照](https://www.monotaro.com/g/02255191/) |
| ELEC_U5 | クランプ比較器<br>LM393GN／バス過電圧検出 | 1個 | 1個×1 | 30円 | 販売表示・条件付き | [参照](https://akizukidenshi.com/catalog/g/g116987/) |
| ELEC_U6 | クランプ基準電圧IC<br>TL431A (HTC)／基準2.495V、調整必要 | 1個 | 1個×1 | 20円 | 販売表示・条件付き | [参照](https://akizukidenshi.com/catalog/g/g112018/) |
| ELEC_QCLAMP | クランプMOSFET<br>2SK2232／抵抗のON/OFFスイッチ | 1個 | 1個×1 | 100円 | 販売表示・条件付き | [参照](https://akizukidenshi.com/catalog/g/g102414/) |
| ELEC_PS2 | クランプ制御用レギュレータ<br>LM78L12／12V、モーターバスから給電 | 1個 | 1個×1 | 20円 | 販売表示・条件付き | [参照](https://akizukidenshi.com/catalog/g/g113464/) |
| ELEC_D0 | 電池への逆流防止ダイオード<br>SBM1060LSS／60V 10A、10個入り | 1個 | 10個入り×1 | 300円 | 販売表示・条件付き | [参照](https://akizukidenshi.com/catalog/g/g116378/) |

## 送料

| ID | 品名・仕様 | 使用数 | 購入予定単位 | 明細金額 | 価格根拠 | 購入先・仕様 |
| --- | --- | --- | --- | --- | --- | --- |
| S02 | キャスター送料 | 1式 | 送料／諸費1式 | 0円 | 販売表示・条件付き | [参照](https://www.aboutamazon.jp/news/guide/answer-to-7-questions-about-shopping-at-amazon) |
| S03 | フレーム・残存素材の追加送料枠 | 1式 | 送料／諸費1式 | 1,000円 | 予算枠 | 未確定 |
| S04 | 純正接合部・溝ナットの送料枠 | 1式 | 送料／諸費1式 | 500円 | 予算枠 | 未確定 |
| S06 | タイヤ国内通常送料 | 1式 | 送料／諸費1式 | 0円 | 販売表示・条件付き | [参照](https://www.switch-science.com/policies/shipping-policy) |
| S07 | Taobao送料・輸入諸費 | 1式 | 送料／諸費1式 | 未見積 | 未見積 | 未確定 |
| DECK_CNC_SHIP | D2荷台板 日本宛UPS表示送料<br>UPS Worldwide Express Saver | 1式 | 送料／諸費1式 | 9.98 USD | 実サイト自動見積 | [参照](https://jlccnc.com/jp/cnc-machining-quote) |
| DECK_SHIP | 荷台材料の送料参考 | 1式 | 送料／諸費1式 | 1,200円 | 販売表示・条件付き | 未確定 |
| S08 | CNC日本宛送料 | 1式 | 送料／諸費1式 | 7.23 USD | 実サイト自動見積 | [参照](https://jlccnc.com/jp/cnc-machining-quote) |

## 締結部品の数量明細

以下は上のセット・一式予算の内訳です。金額を追加加算しません。荷台用M6平座金と基礎部用の座金は寸法が異なるため別行です。

| 仕様 | 使用数 | セット付属 | 別途必要数 | 計上先 |
| --- | --- | --- | --- | --- |
| 2.7x5x0.5 steel plain washer | 6 | 0 | 6 | MW |
| HNTT6-6 slot nut | 50 | 16 | 34 | DECK_fasteners_and_extra_slotnuts, F03, F04 |
| M2.5x12 socket screw | 6 | 0 | 6 | H01 |
| M3 plain hex nut | 4 | 0 | 4 | FIXTURE_HARDWARE |
| M4 large washer 12x4.3x1 | 8 | 0 | 8 | FIXTURE_HARDWARE |
| M4 plain hex nut | 16 | 0 | 16 | DECK_fasteners_and_extra_slotnuts, FIXTURE_HARDWARE |
| M4 plain washer 9x4.3x0.8 | 48 | 0 | 48 | DECK_fasteners_and_extra_slotnuts, FIXTURE_HARDWARE |
| M4x16 socket screw | 8 | 0 | 8 | FIXTURE_HARDWARE |
| M4x25 socket screw | 8 | 0 | 8 | DECK_fasteners_and_extra_slotnuts |
| M6 JIS B1256 grade A washer 12x6.4x1.6 | 12 | 0 | 12 | DECK_fasteners_and_extra_slotnuts |
| M6 large washer OD18 ID6.6 t1.6 | 12 | 0 | 12 | H01 |
| M6 plain hex nut | 4 | 0 | 4 | H01 |
| M6 washer OD13 ID6.6 t1.6 | 12 | 0 | 12 | H01 |
| M6x10 socket screw | 8 | 0 | 8 | H01 |
| M6x12 socket screw | 36 | 16 | 20 | F03, H01 |
| M6x16 socket screw | 4 | 0 | 4 | H01 |
| M6x30 socket screw | 6 | 0 | 6 | DECK_fasteners_and_extra_slotnuts |
| タイヤキット付属ねじ（寸法未公表） | 6 | 6 | 0 | D02 |

M6×12は36本のうち16本が接合SET付属、追加20本です。タイヤ付属ねじ6本は寸法未公表・CAD個別形状なしで、モーター固定用M2.5×12の6本とは別です。締結材の販売パック・強度区分・厚さ選別は未確定部分が残ります。

## 製作品

素材の購入費は親の費用行に含みます。専用モーター金具とD2荷台板はCNC外注。支持ブロック・ストッパ・他の板材は自加工前提で、工具・工賃は未計上です。

| 部品 | 数量 | 材質・寸法 | 製作 | 材料・費用行 | 設計資料 |
| --- | --- | --- | --- | --- | --- |
| 専用モーター金具 | 2 | A6061-T6／90×30×34mm | CNC外注 | Q01 | [資料](M0601C_mount_A6_R1.step) |
| キャスター取付板 | 1 | A5052／80×170×4mm | 自加工 | P01 | [資料](AMR01_M0601C_A6.FCStd) |
| コーナーガセット | 4 | A5052／直角二辺60mm・t3 | 自加工 | P03 | [資料](AMR01_M0601C_A6.FCStd) |
| 格子穴荷台板 D2 | 1 | 6061-T6／300×300×4mm | CNC外注 | DECK_plate | [資料](aluminum-grid-deck/AMR_GridDeck_C45_D2.pdf) |
| 荷台支持ブロック | 6 | アルミ／20×15×15mm | 自加工 | DECK_square_bar | [資料](DECK_REVIEW.ja.md) |
| 荷物ストッパ | 4 | アルミ／15×15×50mm | 自加工 | DECK_square_bar | [資料](DECK_REVIEW.ja.md) |
| 電池クレードル | 1 | PLA／130×160×37mm | P1Sで印刷 | P04 | [資料](AMR01_M0601C_A6.FCStd) |
| 後部電装トレイ | 1 | PLA／85×180×4.4mm | P1Sで印刷 | P04 | [資料](AMR01_M0601C_A6.FCStd) |
| 前部電装トレイ | 1 | PLA／145×170×4.4mm | P1Sで印刷 | P04 | [資料](AMR01_M0601C_A6.FCStd) |
| 小型機器用アダプタ | 2 | PLA／64×16×3.2mm | P1Sで印刷 | P04 | [資料](printed-accessories/README.ja.md) |
| 配線ガイド | 2 | PLA／64×23×12mm | P1Sで印刷 | P04 | [資料](printed-accessories/README.ja.md) |

角棒は995mmを1本購入し、20mm×6個と50mm×4個へ切断します。必要完成長320mm、切りしろ30mmの想定です。PLA7部品はP1Sの造形範囲内ですが、実スライスは未実施です。

## 未選定・未見積

| ID | 必要なもの | 数量 | 残る決定 | 段階 |
| --- | --- | --- | --- | --- |
| U01 | 電池・保護回路・接続アダプター | 1式 | セル保護・電流・コネクタ・120×80×65mm予約との適合を確定 | 走行台車 |
| U02 | 適合充電器 | 1台 | 車体から分離充電。電池と同時選定 | 走行台車 |
| U03 | 上位計算機・記憶媒体・冷却 | 1式 | 現在の0.50kg枠への収まりを確認。外部PCを流用する場合は購入除外を明記 | 走行台車 |
| U04 | 上位計算機用DC/DC | 1台 | 監視用5V/1Aとは別回路 | 走行台車 |
| U05 | ARM押ボタン | 1個 | 接点・デバウンスを確定 | 走行台車 |
| U06 | 主電源スイッチ・主コネクタ | 1式 | 電池・突入電流・抜け止め条件に合わせる | 走行台車 |
| U07 | ヒューズ・ホルダー | 5回路＋計算機系 | DC遮断定格、突入、線材許容電流で型式と数量を確定 | 走行台車 |
| U08 | 制御・分配基板とコネクタ | 1式 | 候補ICを実装するための基板、端子台、取付を確定 | 走行台車 |
| U09 | リレーコイル駆動・保護部品 | 2回路分 | 実回路の部品型式・定数・数量を確定 | 走行台車 |
| U10 | レベル変換・デバウンス・電源投入リセット | 1式 | 回路確定後に受動部品まで展開 | 走行台車 |
| U11 | 抵抗・コンデンサ・終端抵抗 | 1式 | 値の候補は回路資料にあるが実装数量・終端内蔵有無未確定 | 走行台車 |
| U12 | 電圧・電流計測部品 | 1式 | 実装回路・測定レンジ・校正を確定 | 走行台車 |
| U13 | 電源線・信号線・圧着端子・結束材 | 長さ・個数未定 | 配線図と実経路から線長・端子数を確定。工場付属ハーネスとの重複を避ける。今回の配線ガイド用結束バンド2本はFIXTURE_HARDWARE計上済み。 | 走行台車 |
| U14 | 放熱固定具・ガード・絶縁材 | 1式 | 放熱面・端子カバー・温度を確認 | 走行台車 |
| U15 | 電装固定板・ケース・スタンドオフ | 数量未定 | 実機器の穴配置・放熱・M3ねじ長・最終配線を確定。汎用小物の追加だけで全電装の適合確認済みとはしない。 | 走行台車 |
| U16 | 未確定送料・税・決済換算 | 1式 | 送料行で計上済みの分を重複加算しない | 走行台車 |
| U17 | 加工工具・作業費・残る自加工品の外注費 | 必要に応じて | モーター金具とD2上板は実自動見積あり。支持材・ストッパ・キャスター板・ガセットの工具・工賃は未見積。 | 走行台車 |
| U18 | PLA仮合わせモックの材料消費 | スライス後 | P04の車体用300g枠とは別。印刷時間・材料量未確定 | 製作補助 |
| U19 | 自律移動用LiDAR・IMU・カメラ等 | 未選定 | 今回の小計は走行台車と電装候補。自律移動一式の完成価格ではない | 将来自律移動 |
| U20 | 荷物容器・敷板 | 1式 | 荷台上の積載物として重量算入。手持ち品利用可 | 積載物 |

追加機械ブレーキ、旧USB-RS485B、既製の背の高いモーターブラケットは現行購入対象に含みません。通常の減速・停止用のモーター制御と回生対策は電装候補へ含めています。

## データと更新

[数量・購入条件の入力](bom_inputs.json)、[費用台帳](bom.json)、[生成BOM JSON](procurement_bom.json)、[CAD対応表](BOM_CAD_MAP.csv)。CADはD2荷台とPLA小物へ更新しました。モーター金具の見積STEP/PDFは維持しています。

```sh
python3 cad/amr07/record_cost.py
python3 cad/amr07/build_bom.py
# Excelも更新する場合（openpyxl 3.1.5）
python3 cad/amr07/build_bom.py --xlsx
```

Excel・CSVは生成物です。数量・購入条件はbom_inputs.json、費用はrecord_cost.pyとその参照元へ変更を反映してから再生成してください。bom.jsonはrecord_cost.pyで上書きされます。Excelの金額空欄は未見積で、概要の合計は既知金額だけの途中小計です。

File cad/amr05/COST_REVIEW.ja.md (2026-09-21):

**A4 M0601C_111のブラケット製作・購入費用方針 — 2026-09-21**

M0601C_111を採用し、**既製品の特殊な固定受けの設計を踏襲した低背の一体アルミLブラケットを製作依頼する案**を主案として具体化する。ユーザーは既製品だけでなく、設計データから作って依頼する方法も認めている。既製DDT-M0601C-BRACKET＋3030側取付板は比較案として残す。製作案のSTEPと寸法図を整えて左右2個分を見積もり、価格を創作せずに比較する。

モーター約7,000円／個はユーザーが示したTaobao購入の仮枠であり、国内販売価格やタイヤ付き一式の確定額ではない。現行の[BOM](BOM.csv)は**本体のみ＋初回タイヤ別購入**を基準とし、円の参考価格・仮枠小計は**42,282円**。これに、JLCCNCへ実STEP/PDFを投入した**金具2個74.50 USD＋日本宛OCS送料7.23 USD＝81.73 USDの自動見積**を別通貨で計上する。[見積条件と証拠画面](MACHINING_QUOTE.ja.md)。正式審査、税・住所別送料・決済換算、Taobao諸費が未確定のため、[費用集計](cost_summary.json)の円総額と予備費込み円総額は`null`のままとする。

製作主案はA6061-T6を希望材質とする同形状2個。見積用[STEP](M0601C_custom_mount_quote.step)と[寸法表](custom_mount_dimensions.json)は包絡90×30×34mm、フランジ90×30×5mm、web60×17×34mm、特殊受け部深さ9mm・背面8mm。左右へ回転配置する。製造公差、受入モーターとの適合と製作価格は未確定で、製造承認済みの図面ではない。

| 費目・個人購入先 | 確認価格／左右分 | 付属品・調達状態 |
| --- | ---: | --- |
| TaobaoのM0601C_111 | 約7,000円／14,000円の仮枠 | 対象URL・選択SKU・タイヤ／カバー／ねじ／ケーブルの付属、国内外送料・代行手数料・輸入諸費は未確認。7,000円を着荷総額にしない |
| [国内M0601C_111](https://www.switch-science.com/products/7646) | 税込14,410円／28,820円 | 確認時は在庫0・売切れ。国内比較では本体とタイヤキットを別計上する |
| [DDT-M0601C-BRACKET](https://www.switch-science.com/products/9204) | 税込6,050円／12,100円 | 在庫6表示。115×70×25mm、アルミ。内容物欄はブラケット1個のみで、取付ねじの付属は記載なし。ねじ代を無料と仮定しない |
| [DDT-M0601C-TIRE](https://www.switch-science.com/products/9203) | 税込4,620円／9,240円 | 在庫6表示。M0601C_111への適合を明示。1キットにタイヤ1・カバー1・ねじ3。タイヤ寸法100.7×100.7×43mm |

以上は2026-09-21に販売ページを直接確認した表示値で、未発注・在庫未確保。ブラケットの12,100円は国内購入額で、Taobaoの金具価格ではない。国内金具2個、または交換タイヤキット2個の同時購入は、[8,000円以上の通常送料無料条件](https://www.switch-science.com/policies/shipping-policy)を満たす。輸入分の送料へこの条件を流用しない。タイヤキット1個だけの補修注文は、現行条件なら4,620＋650＝5,270円となる。

別の国内購入経路として[マルツの同型ブラケット](https://www.marutsu.co.jp/pc/i/3656217/)も確認できたが、現在表示は税込6,125円、取り寄せ先在庫6個（9月18日付）だった。検索結果に残る旧価格を採用せず、今回の比較はスイッチサイエンス6,050円を用いる。取り寄せ先表示を独立した在庫の保証とはしない。

**材料・加工・締結材を含む比較方法**

既製品は[元データの調査](BRACKET_SOURCE_REVIEW.ja.md)で高さ115mm、軸より下90mm・上25mm。反転配置でも底面は地上25.35mm、上端は140.35mmとなり、旧地上高25mm目標に対する公称差は0.35mmにとどまる。[配置検査](stock_bracket_fit_results.json)では元のレールとの干渉が残った。固定面138とt5取付板を守る案では外レール24mm内寄せと接合金具の再配置が必要になり、その成立・費用は未確定。荷重変形やタイヤのたわみを含む成立保証でもない。既製品価格だけで採用を決めず、配置するための部材・作業も評価する。

基準は[A3のBOM](../amr04/bom.json)と[費用集計](../amr04/cost_summary.json)。自加工47,824円からDDSM115一式25,982円、自作上アングル1,000円、下アングル1,000円、鋼製キー板800円を取り外すと、共通費の暫定残額は**19,042円**になる。新しい製作ブラケットまたは既製ブラケットを排他的に加え、旧自作固定部2,800円を重ねて残さない。

製作ブラケットの自動見積は、同形2個・A6061-T6・表面処理なし・受け部±0.05mmのPDF添付・製造10日で取得した。以下は国単位の送料を加えた81.73 USDを用いる。既製品用3030取付板2枚の素材・穴加工一式`P`は未見積で、0円ではない。

| 初回の購入条件 | 低背一体ブラケットを製作依頼する主案 | 既製ブラケット2個＋取付板の比較案 |
| --- | ---: | ---: |
| Taobao約7,000円に適合タイヤ一式を含むと確認できた場合 | **33,042円＋81.73 USD＋残る未確定分** | **45,142円＋P＋残る未確定分** |
| Taobao約7,000円にタイヤを含まず、国内キット2個を追加 | **42,282円＋81.73 USD＋残る未確定分** | **54,382円＋P＋残る未確定分** |
| 国内表示の本体＋キット、ただし本体欠品 | **57,102円＋81.73 USD＋残る未確定分** | **69,202円＋P＋残る未確定分** |

残る未確定分は国内外配送・手数料、発注単位確定後の仮枠差額、残る板部品も外注する場合の加工費など。既製案は取付板・締結の配置数量も未確定。表の数値は最終額や実費範囲ではない。タイヤ付きが未確認の段階では、その付属を理由に9,240円を削らない。逆に付属が確認できれば初回分を二重計上せず、予備・交換キットとは区別する。

旧外注追加枠6,000円は自作アングルの脚切詰め、内R逃げ、鋼製キー異形輪郭などを含む未見積値だった。A4ではこの枠を削除し、**製作ブラケットと残存板部品の作業範囲ごとの見積へ置換**する。上記19,042円は元から旧外注6,000円を含まない。ブラケット見積に材料が含まれる場合は別のアルミ素材代を重ねず、含まれない場合にだけ追加する。キャスター板・ガセットの素材は共通費に残り、その加工が残ることを忘れない。既製案では取付板素材・穴加工も必要。自加工の自己作業費と新規工具代は別。

見積依頼には部品版、STEP、寸法図、左右2個、材質、重要な固定受けの寸法・公差、ねじ穴と面取り、材料・加工・バリ取りの希望範囲をそろえる。納入寸法の検査、送料・税の扱いも確認し、要求精度と価格の両方で比較する。完成ブラケットの材料込み見積と、材料だけの仮枠を直接比較しない。81.73 USDと12,100円は決済換算・税・送料条件を揃えて比較し、既製案の取付板・加工・締結費も含めて優劣を決める。

一般締結材2,300円と追加溝ナット28個分1,200円は共通費19,042円に含む仮枠。[最終fasteners.csv](fasteners.csv)で、主案の溝ナット44個＝SET付属16＋追加28、一般締結材の追加66点を照合した。モーター固定はM2.5×12が6本、フレーム固定はM6×12が4本で、A3のM4ねじ・ナット・ワッシャ各12点は撤去。購入パックの単価が不明なため、使用数減少だけで2,300円枠を減らしてはいない。既製比較案の締結数量は別途更新する。

タイヤキットの付属ねじ3本はタイヤ側の費目であり、ブラケット・3030固定ねじを兼ねると推定しない。通信インターフェース・USBケーブルも共通費へ残すが、通信とソフトウェアの適合は別確認。電池・主計算機・電源保護・非常停止・車内配線等の未選定費用を0円とは扱わない。

**交換費用の考え方**

適合が明示されたタイヤキットを購入できる点は、タイヤ単体の供給が未確認だったDDSM115案からの改善になる。ただし販売単位はゴム単体ではなくカバー・ねじ付きキットで、現時点の補修予算は**左右1回9,240円、2回18,480円**。ブラケットや正常なモーター本体を毎回買い直す費用は加えない。将来の在庫・価格・供給期間、実使用での寿命は未保証であり、何年で何回交換するかは実機の摩耗記録から決める。

初期比較には最初に装着するタイヤを必ず含め、維持費比較にはその後の交換分だけを加える。Taobao品は、同一型式・販売仕様と国内補修キットの適合を確認してからこの維持費へ接続する。国内本体欠品や未確認の輸入諸費を隠して、安いモーター単価だけで完成台車が安くなるとは結論しない。

**A4専用費用計算器**

[A3計算器](../amr04/calculate_cost.py)は全行に数値の購入価格があることを前提としていたため、[A4計算器](calculate_cost.py)には未知価格を保持する集計を実装した。`python3 cad/amr05/calculate_cost.py --require-cad --self-test`でBOM.csvとcost_summary.jsonを再生成できる。CSVは基準案の購入15行だけを出力し、比較案を一緒に発注する表にはしない。A3ファイルは履歴として変更していない。

| 項目 | A4での扱い |
| --- | --- |
| 共通BOM | 3030、純正接合部、キャスター、PLA、ストラップ、USB通信等を1回だけ計上。主案のCADと締結数量・見積形状・PLA3点を照合 |
| 調達条件 | モーターはTaobao仮枠／国内欠品参考を別シナリオ。Taobaoタイヤ付属は`unverified`のまま、付属確認時と別購入時を分ける |
| 主案の製作行 | 左右2個を1式とし、`packs=1, pieces_per_pack=2, used=2`。`pack_price_foreign`に74.50 USD、`price_kind=vendor_auto_quote_2026_09_21`。円換算は未確定なので`pack_price_jpy=null`。2個分を再び2倍しない |
| 既製比較行 | 国内ブラケット2個12,100円と取付板素材・穴加工を計上。主案の製作行とは同時に加算しない |
| 価格根拠 | 確認済み販売値、旧記録、公式表参考、ユーザー仮枠、業者自動見積、未見積を区別。自動見積を審査後の確定額としない。Taobao仮枠へ「税込確認済み」を付けず、輸入諸費の未確認行を残す |
| 加工範囲 | 希望する見積範囲を保存し、受領後は実際に含む材料・加工・税・送料を記録。見積範囲に合わせて重複する素材・配送行を更新する |
| 未知価格・外貨 | 未見積と外貨取得済みの円換算待ちを別一覧にする。円小計42,282、外貨小計USD 81.73を合算しない。いずれかが残れば円総額・A3総差額・予備費込み円総額は`null` |
| CSV・比較 | 未見積は「見積待ち」、外貨取得済みの円セルは「円換算未確定」、原通貨列にUSD/74.50を表示。各シナリオの有効行だけを合計し、A3から削除／引継ぎ／置換／追加した全行を照合 |
| 保守費 | 初期タイヤと後の交換キットを分離。左右1回9,240円・2回18,480円のキット費を別出力し、初期総額が未定のまま台車全体の累計額を作らない |

未見積の製作行だけを残した場合と、外貨の円換算待ちだけを残した場合の双方で円総額が`null`になることを確認した。2個一式74.50 USDと送料7.23 USDを各1回のみ計上し、タイヤ付属時との差9,240円も検査した。最終CADの締結8種類・溝ナット44個・追加一般締結66点・PLA3点との照合も通過した。10%予備費は見積待ち費用を代用する数字にはしない。

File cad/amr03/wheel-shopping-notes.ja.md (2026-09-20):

**150 mm 駆動輪の短時間調達調査 — 2026-09-20**

結論：国内の個人向け通販で購入手続きへ進める150 mm鋼製ゴム車輪は確認できた。ただし、既存の8 mm軸・4×M3／PCD24フランジハブでそのまま駆動できる製品は確認できていない。Aと同シリーズの「150×25.4 mm、金属＋ネオプレン、穴8 mm」のAmazon商品・価格・在庫は、今回の約6分の調査では未確認。150 mm化を調達確定としてCADへ織り込む根拠にはしない。購入・販売店への問い合わせは実施していない。

| 候補 | 確認できた寸法・材質 | 掲載価格と購入経路 | 駆動輪としての判定 |
| --- | --- | --- | --- |
| ハンマーキャスター 430E-PR150 | 外径150、タイヤ幅22、ボス幅30、穴径8.2 mm。鋼製ホイール、ゴム、樹脂ブッシュ。ゴムがネオプレンであることは未確認 | [Yahoo!／プロキュアエース](https://store.shopping.yahoo.co.jp/procure-a/814-1327.html)：1,057円／個＋送料660円表示。2個を送料1回で同梱できる場合は2,774円。9/25〜9/28発送予定表示 | 自由回転する交換用車輪。軸との駆動固定機構がないため追加設計が必要 |
| 同上・別販売店 | 同上 | [Yahoo!／工具の楽市](https://store.shopping.yahoo.co.jp/kougurakuichi/8141327.html)：1,111円／個＋東京都送料770円表示。2個同梱なら2,992円。9/25発送予定表示 | 同上 |
| uxcell 150×32 mm 樹脂輪 | 穴8 mm、販売表示80 g | [楽天／uxcell](https://item.rakuten.co.jp/uxcelljapan/a17051700ux0013/)：検索表示1,618円。中国からの個人輸入扱い | 軽量な樹脂輪で、荷重・駆動固定の裏付けがないため今回の候補から除外 |

価格は取得時の掲載値で、ポイント・クーポンを差し引いていない。2個の送料は未決済の仮計算。実在庫・最終送料・納期は注文確認画面で未確認。Yahoo!の一般向け商品ページに購入ボタンがあり、法人専用とは表示されていなかった。

430E-PR150の寸法と材質は[メーカー車輪詳細](https://hammer-caster.co.jp/products/wheel/1938/430E-PR/150)で照合した。[メーカー寸法図](https://hammer-caster.co.jp/photo/DrawingSyarin/Drw-430_00E_0PR_065-150.gif)も閲覧したが、示されるのはD／W／H／dの断面であり、駆動ハブ用の穴配置や中央ウェブ板厚は分からない。これはボールベアリング入り駆動輪ではなく、樹脂ブッシュを持つキャスター用自由輪である。

転用には、8 mm軸を既存KP08で支持し、軸に固定したフランジハブから金属ウェブへトルクを伝える締結が必要になる。穴径8.2 mmのブッシュへ軸を通すだけでは駆動できない。既存ハブの4×M3／PCD24が使えるかは、中央の成形ボス径、平坦な締結面、板厚、リベット位置、工具の入る空間を調べる必要がある。追加穴加工の可否と強度、軸方向30 mmのボスとハブ・カラーの積み重ねも未確定。完成キャスターの荷重表示を、加工後の駆動輪の定格として流用しない。

低床化の比較計算は次のとおり。単位はmm、地面をz=0とする。

- D150の車軸高さは75。フレームz=26〜56、上の取付板t4、KP08の軸高15なら、26＋30＋4＋15＝75となり、40 mmスペーサを使わない上面支持を配置できる。
- フレーム下面はAの75から26へ49 mm下がる。これは軸受配置の寸法関係のみの確認であり、モーター・カプラ・後輪・機器との干渉と地上高は別途成立させる必要がある。
- 同じ推進力では必要車軸トルクが150/100＝1.5倍になる。14 kg条件でAの0.708 N·m／輪を使うと約1.062 N·m／輪。FIT0185でこの連続運転が成立することは未確認。
- 同じ83 rpmなら幾何学上の速度は0.435から0.652 m/sへ増える。実走行速度や連続性能を保証する数値ではなく、径を変える場合は速度指令も見直す。

Amazon優先で日本語・英語の150／152 mm、25.4 mm、金属、ネオプレン、ロボット車輪を調べたが、Aの[100 mm品](https://www.amazon.co.jp/dp/B0B23WBLBK)に対応する150 mm品は特定できなかった。Amazon検索の直接取得もHTTP 503となったため、未確認として打ち切った。現段階では100 mmを維持する直接支持案も並行比較し、150 mm案は「車輪ウェブへの確実な駆動締結」と「増加トルクへの対応」が確認できた場合の候補とする。

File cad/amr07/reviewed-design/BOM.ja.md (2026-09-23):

# E4 BOM：標準構成のみ

**計上済み小計 88,560円相当＋未計上分**（75,625円＋82.25 USD）。モニターは含めません。

**天板の穴配置を変更したため、旧天板見積38.65 USDは現行小計から外しました。この減少を節約額とは扱いません。** 新天板・送料は実再見積待ちです。

[全明細Markdown](BOM-details.ja.md) ／ [CSV](BOM.csv) ／ [オプション専用BOM](../monitor-option/BOM.ja.md)

為替は既存の2026-09-21参考値157.2672円/USDで、決済レートではありません。旧価格・仮予算は各明細に残しています。PC・給電・HAT・最終配線等も未計上です。

| 部位 | 計上済み円換算 | 小計内割合 |
|---|---:|---:|
| モーター・タイヤ・キャスター | 24,413円 | 27.6% |
| 電池・充電器 | 23,380円 | 26.4% |
| フレーム・締結・PLA等 | 23,016円 | 26.0% |
| モーター金具 | 12,935円 | 14.6% |
| 電装・配線 | 4,288円 | 4.8% |
| 天板 | 528円 | 0.6% |

| 部品 | 使用数 | 購入数 | 計上額 |
|---|---:|---:|---:|
| [3030フレーム 400mm](BOM-details.ja.md#item-f01) | 4 | 4 | 1952 JPY |
| [3030フレーム 300mm](BOM-details.ja.md#item-f02) | 4 | 4 | 1467 JPY |
| [自在キャスター](BOM-details.ja.md#item-c01) | 1 | 1 | 273 JPY |
| [キャスター取付板の素材](BOM-details.ja.md#item-p01) | 1 | 未定 | 900 JPY |
| [ダイレクトドライブモーター](BOM-details.ja.md#item-d01) | 2 | 2 | 14000 JPY |
| [タイヤ・カバーキット](BOM-details.ja.md#item-d02) | 2 | 2 | 9240 JPY |
| [A6-R1専用モーター金具](BOM-details.ja.md#item-q01) | 2 | 2 | 75.02 USD |
| [荷物固定ベルト](BOM-details.ja.md#item-deck_cargo_straps) | 2 | 2 | 786 JPY |
| [ベルト接触部の保護材・余長固定](BOM-details.ja.md#item-deck_edge_protection_and_slack_retention) | 1 | 未定 | 300 JPY |
| [電池モジュール保持ベルト](BOM-details.ja.md#item-h02) | 1 | 1 | 393 JPY |
| [基礎部の追加ねじ・ナット・座金](BOM-details.ja.md#item-h01) | 1 | 未定 | 2300 JPY |
| [モーター座面用小径平座金](BOM-details.ja.md#item-mw) | 6 | 10 | 319.0 JPY |
| [LinuxミニPC–Pico用USBデータケーブル](BOM-details.ja.md#item-e02) | 1 | 未定 | 500 JPY |
| [手持ちRaspberry Pi Pico](BOM-details.ja.md#item-elec_u1) | 1 | 0 | 0 JPY |
| [キャスター送料](BOM-details.ja.md#item-s02) | 1 | 未定 | 0 JPY |
| [フレーム・残存素材の追加送料枠](BOM-details.ja.md#item-s03) | 1 | 未定 | 1000 JPY |
| [純正接合部・溝ナットの送料枠](BOM-details.ja.md#item-s04) | 1 | 未定 | 未計上 |
| [タイヤ国内通常送料](BOM-details.ja.md#item-s06) | 1 | 未定 | 0 JPY |
| [Taobao送料・輸入諸費](BOM-details.ja.md#item-s07) | 1 | 未定 | 未計上 |
| [CNC日本宛送料](BOM-details.ja.md#item-s08) | 1 | 未定 | 7.23 USD |
| [純正反転ブラケット本体](BOM-details.ja.md#item-f03) | 20 | 20 | 1834 JPY |
| [車体全体の先入れ溝ナット](BOM-details.ja.md#item-f04) | 70 | 100 | 5112 JPY |
| [フレーム用M6×12キャップボルト](BOM-details.ja.md#item-d3_m6) | 44 | 70 | 2360 JPY |
| [床・ケース用M4ナット](BOM-details.ja.md#item-d3_stop_nuts) | 20 | 20 | 273 JPY |
| [床・PCカバー・操作部・PicoケースのPLA](BOM-details.ja.md#item-p04) | 905 | 0 | 1810 JPY |
| [荷物固定ベルト送料参考](BOM-details.ja.md#item-d3_strap_ship) | 1 | 未定 | 600 JPY |
| [固定式格子穴アルミ天板](BOM-details.ja.md#item-deck_plate) | 1 | 1 | 未計上 |
| [アルミ天板1枚の日本宛送料](BOM-details.ja.md#item-deck_cnc_ship) | 1 | 未定 | 未計上 |
| [純正電池＋急速充電器](BOM-details.ja.md#item-power_kit) | 1 | 1 | 19800 JPY |
| [電池・充電器セット送料](BOM-details.ja.md#item-power_kit_ship) | 1 | 1 | 600 JPY |
| [電池出力アダプター](BOM-details.ja.md#item-power_adapter) | 1 | 1 | 2180 JPY |
| [アダプター送料](BOM-details.ja.md#item-power_adapter_ship) | 1 | 1 | 800 JPY |
| [電池・電装の軟質当て材](BOM-details.ja.md#item-power_pads) | 1 | 1 | 未計上 |
| [1階計算機の保持ベルト](BOM-details.ja.md#item-power_low_straps) | 1 | 未定 | 未計上 |
| [100mm溝付き支柱4本](BOM-details.ja.md#item-d6_posts) | 4 | 4 | 495 JPY |
| [床・ケース用M4×16](BOM-details.ja.md#item-d62_floor_screws) | 20 | 60 | 770 JPY |
| [継ぎ目支持梁端の大径平座金](BOM-details.ja.md#item-d62_beam_washers) | 4 | 未定 | 未計上 |
| [床・ケース用M4 OD12×t1座金](BOM-details.ja.md#item-d64_floor_washers) | 24 | 40 | 860 JPY |
| [中央ねじ・座金の別店舗送料](BOM-details.ja.md#item-d64_fastener_ship) | 1 | 1 | 385 JPY |
| [車載LinuxミニPC・記憶媒体・必要な冷却](BOM-details.ja.md#item-u03) | 未定 | 未定 | 未計上 |
| [車載LinuxミニPC用の給電部材](BOM-details.ja.md#item-u04) | 未定 | 未定 | 未計上 |
| [電源着脱・分岐コネクタ](BOM-details.ja.md#item-u06) | 未定 | 未定 | 未計上 |
| [ヒューズ・ホルダー](BOM-details.ja.md#item-u07) | 未定 | 未定 | 未計上 |
| [Pico用2チャンネルRS485完成基板](BOM-details.ja.md#item-u08) | 未定 | 未定 | 未計上 |
| [端末加工済み電源・信号ハーネス](BOM-details.ja.md#item-u13) | 未定 | 未定 | 未計上 |
| [電装固定板・ケース・スタンドオフ](BOM-details.ja.md#item-u15) | 未定 | 未定 | 未計上 |
| [未確定送料・税・決済換算](BOM-details.ja.md#item-u16) | 未定 | 未定 | 未計上 |
| [加工工具・作業費・残る自加工品の外注費](BOM-details.ja.md#item-u17) | 未定 | 未定 | 未計上 |
| [PLA仮合わせモックの材料消費](BOM-details.ja.md#item-u18) | 未定 | 未定 | 未計上 |
| [荷物容器・敷板](BOM-details.ja.md#item-u20) | 未定 | 未定 | 未計上 |
| [全電源の主スイッチ](BOM-details.ja.md#item-elec_main) | 1 | 1 | 621 JPY |
| [非常停止スイッチ HW1B-V402R](BOM-details.ja.md#item-u22) | 1 | 1 | 2387 JPY |
| [非常停止スイッチ送料（住所未照合）](BOM-details.ja.md#item-e3_estop_ship) | 1 | 1 | 780 JPY |
| [Picoケース固定用M3締結材](BOM-details.ja.md#item-u24) | 未定 | 未定 | 未計上 |
| [天板用極低頭M6×12](BOM-details.ja.md#item-e4_lowhead) | 6 | 10 | 528 JPY |
| [ケース内配線の保持・表示用品](BOM-details.ja.md#item-e4_terminal_retention) | 1 | 未定 | 未計上 |
| [極低頭ボルトの送料](BOM-details.ja.md#item-e4_lowhead_ship) | 1 | 未定 | 未計上 |

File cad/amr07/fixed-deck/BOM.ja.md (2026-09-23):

# E3 BOM（Pico＋RS485基板・直接非常停止）

**通信は手持ちPico＋ユーザー提示RS485基板。非常停止はHW1B-V402Rの左右別接点。実配線・電源適合は確認待ちです。** [最小構成](../electrical-buildability/README.ja.md)。

**途中小計 94,466円相当＋未計上分**。原通貨：75,452円＋120.90 USD。

[全明細Markdown](BOM-details.ja.md) ／ [CSV](BOM.csv) ／ [加工見積の証拠](MACHINING_QUOTE.ja.md)

旧専用回路部品とはんだ端子の非常停止、計6,519円を[価格履歴](../electrical-buildability/withdrawn-parts.ja.md)へ移しました。通信基板・最終ハーネス等が未計上なので、この減額は節約ではありません。割合も完成車の費用割合ではありません。

E3でARM計835円と、追加監視等を初回必須から外しました。全電源用の主スイッチ621円は復帰しています。[条件付き・後工程の部品](../electrical-buildability/deferred-parts.ja.md)は下の必須未計上品へ混ぜていません。

円換算は記録済みの2026-09-21参考値1 USD＝157.2672円。現在の決済額ではありません。購入パック全額を計上し、余りを按分していません。車載LinuxミニPC・給電部材・Pico用RS485基板・ヒューズ・配線などは未計上、モーター14,000円とUSB線500円は仮予算、PLAは材料消費の参考です。計算機はLinuxミニPCを想定し、機種は固定しません。非常停止は2,387円＋東京向け送料780円を計上、基板のAmazon表示価格は未取得です。

機械部分はヒンジ案D6.8から約15,547円減。ヒンジ・専用L金具・蝶ボルト等の購入を削除。M6固定6点は既計上パックの余りを使い、新規パック購入なし。天板は同一形状のD3実自動見積を再使用。E3のPLA増加を反映し、既存価格は再取得していません。

| 部位 | 円換算参考 | 計上済み分の割合 |
|---|---:|---:|
| 電池・充電器・アダプター | 23,380円 | 24.7% |
| フレーム・締結材・共通送料 | 20,000円 | 21.2% |
| モーター | 14,000円 | 14.8% |
| モーター専用金具 | 12,935円 | 13.7% |
| タイヤ・キャスター | 10,413円 | 11.0% |
| 天板（固定ボルトは共通締結材） | 6,078円 | 6.4% |
| 操作部・USB線（電装主要部は未計上） | 4,288円 | 4.5% |
| PLA・ベルト | 3,371円 | 3.6% |

Amazonを優先。Prime会員としての最終配送条件は未確認です。既存価格は確認日と仮枠の区別を各明細に残しています。6点固定はM6×12・HNTT6-6を各6個使い、両側から荷台を保持します。

## 電池・充電器・アダプター

| 部品 | 使用／購入 | 原通貨金額 |
|---|---|---:|
| [純正電池＋急速充電器](BOM-details.ja.md#item-power_kit) | 1／1 式 | 19800 JPY |
| [電池・充電器セット送料](BOM-details.ja.md#item-power_kit_ship) | 1／1 式 | 600 JPY |
| [電池出力アダプター](BOM-details.ja.md#item-power_adapter) | 1／1 式 | 2180 JPY |
| [アダプター送料](BOM-details.ja.md#item-power_adapter_ship) | 1／1 式 | 800 JPY |

## フレーム・締結材・共通送料

| 部品 | 使用／購入 | 原通貨金額 |
|---|---|---:|
| [3030フレーム 400mm](BOM-details.ja.md#item-f01) | 4／4 本 | 1952 JPY |
| [3030フレーム 300mm](BOM-details.ja.md#item-f02) | 4／4 本 | 1467 JPY |
| [基礎部の追加ねじ・ナット・座金](BOM-details.ja.md#item-h01) | 1／未定 式 | 2300 JPY |
| [モーター座面用小径平座金](BOM-details.ja.md#item-mw) | 6／10 枚 | 319.0 JPY |
| [フレーム・残存素材の追加送料枠](BOM-details.ja.md#item-s03) | 1／未定 式 | 1000 JPY |
| [純正接合部・溝ナットの送料枠](BOM-details.ja.md#item-s04) | 1／未定 式 | 未計上 |
| [Taobao送料・輸入諸費](BOM-details.ja.md#item-s07) | 1／未定 式 | 未計上 |
| [純正反転ブラケット本体](BOM-details.ja.md#item-f03) | 20／20 個 | 1834 JPY |
| [車体全体の先入れ溝ナット](BOM-details.ja.md#item-f04) | 70／100 個 | 5112 JPY |
| [ブラケット・天板固定ボルト](BOM-details.ja.md#item-d3_m6) | 50／70 個 | 2360 JPY |
| [印刷ストッパ固定ねじ](BOM-details.ja.md#item-d3_stop_bolts) | 8／未定 個 | 未計上 |
| [ストッパ・床継ぎ目用ナット](BOM-details.ja.md#item-d3_stop_nuts) | 28／40 個 | 546 JPY |
| [ストッパ用座金](BOM-details.ja.md#item-d3_stop_washers) | 8／未定 枚 | 未計上 |
| [荷物固定ベルト送料参考](BOM-details.ja.md#item-d3_strap_ship) | 1／未定 個 | 600 JPY |
| [100mm溝付き支柱4本](BOM-details.ja.md#item-d6_posts) | 4／4 本 | 495 JPY |
| [床・ケース用M4×16](BOM-details.ja.md#item-d62_floor_screws) | 20／60 個 | 770 JPY |
| [継ぎ目支持梁端の大径平座金](BOM-details.ja.md#item-d62_beam_washers) | 4／未定 個 | 未計上 |
| [床・ケース用M4 OD12×t1座金](BOM-details.ja.md#item-d64_floor_washers) | 24／40 枚 | 860 JPY |
| [中央ねじ・座金の別店舗送料](BOM-details.ja.md#item-d64_fastener_ship) | 1／1 式 | 385 JPY |

## モーター

| 部品 | 使用／購入 | 原通貨金額 |
|---|---|---:|
| [ダイレクトドライブモーター](BOM-details.ja.md#item-d01) | 2／2 個 | 14000 JPY |

## モーター専用金具

| 部品 | 使用／購入 | 原通貨金額 |
|---|---|---:|
| [A6-R1専用モーター金具](BOM-details.ja.md#item-q01) | 2／2 個 | 75.02 USD |
| [CNC日本宛送料](BOM-details.ja.md#item-s08) | 1／未定 式 | 7.23 USD |

## タイヤ・キャスター

| 部品 | 使用／購入 | 原通貨金額 |
|---|---|---:|
| [タイヤ・カバーキット](BOM-details.ja.md#item-d02) | 2／2 キット | 9240 JPY |
| [自在キャスター](BOM-details.ja.md#item-c01) | 1／1 個 | 273 JPY |
| [キャスター取付板の素材](BOM-details.ja.md#item-p01) | 1／未定 枚 | 900 JPY |
| [キャスター送料](BOM-details.ja.md#item-s02) | 1／未定 式 | 0 JPY |
| [タイヤ国内通常送料](BOM-details.ja.md#item-s06) | 1／未定 式 | 0 JPY |

## 天板（固定ボルトは共通締結材）

| 部品 | 使用／購入 | 原通貨金額 |
|---|---|---:|
| [固定式格子穴アルミ天板](BOM-details.ja.md#item-deck_plate) | 1／1 枚 | 28.67 USD |
| [アルミ天板1枚の日本宛送料](BOM-details.ja.md#item-deck_cnc_ship) | 1／未定 個 | 9.98 USD |

## 操作部・USB線（電装主要部は未計上）

| 部品 | 使用／購入 | 原通貨金額 |
|---|---|---:|
| [LinuxミニPC–Pico用USBデータケーブル](BOM-details.ja.md#item-e02) | 1／未定 本 | 500 JPY |
| [Pico用2チャンネルRS485完成基板](BOM-details.ja.md#item-u08) | 未定／未定  | 未計上 |
| [非常停止スイッチ HW1B-V402R](BOM-details.ja.md#item-u22) | 1／1 個 | 2387 JPY |
| [Picoケース固定用M3締結材](BOM-details.ja.md#item-u24) | 未定／未定  | 未計上 |
| [非常停止スイッチ送料（住所未照合）](BOM-details.ja.md#item-e3_estop_ship) | 1／1 式 | 780 JPY |
| [手持ちRaspberry Pi Pico](BOM-details.ja.md#item-elec_u1) | 1／0 個 | 0 JPY |
| [全電源の主スイッチ](BOM-details.ja.md#item-elec_main) | 1／1 個 | 621 JPY |

## PLA・ベルト

| 部品 | 使用／購入 | 原通貨金額 |
|---|---|---:|
| [床・PCカバー・荷物止め・操作ケース](BOM-details.ja.md#item-p04) | 946／0 g | 1892 JPY |
| [電池モジュール保持ベルト](BOM-details.ja.md#item-h02) | 1／1 本 | 393 JPY |
| [荷物固定ベルト](BOM-details.ja.md#item-deck_cargo_straps) | 2／2 本 | 786 JPY |
| [ベルト接触部の保護材・余長固定](BOM-details.ja.md#item-deck_edge_protection_and_slack_retention) | 1／未定 式 | 300 JPY |
| [電池・電装の軟質当て材](BOM-details.ja.md#item-power_pads) | 1／1 式 | 未計上 |
| [1階計算機・監視回路の保持ベルト](BOM-details.ja.md#item-power_low_straps) | 2／未定 本 | 未計上 |

## 未計上品

| 部品 | 状態 |
|---|---|
| 純正接合部・溝ナットの送料枠 | 送料未確定 |
| Taobao送料・輸入諸費 | 未見積 |
| 印刷ストッパ固定ねじ | 寸法選定済・実機検証前 |
| ストッパ用座金 | 寸法選定済・実機検証前 |
| 電池・電装の軟質当て材 | 型式選定・現物／電気検証前 |
| 1階計算機・監視回路の保持ベルト | 型式選定・現物／電気検証前 |
| 継ぎ目支持梁端の大径平座金 | 寸法選定済・購入パック未確定 |
| 車載LinuxミニPC・記憶媒体・必要な冷却 | 車載Linux機を使用、機種と価格は未確定 |
| 車載LinuxミニPC用の給電部材 | 初回必須、型番・価格未確定 |
| 電源着脱・分岐コネクタ | 走行台車／未選定 |
| ヒューズ・ホルダー | 走行台車／未選定 |
| Pico用2チャンネルRS485完成基板 | 完成品構成へ再選定・未計上 |
| 端末加工済み電源・信号ハーネス | 完成品構成へ再選定・未計上 |
| 電装固定板・ケース・スタンドオフ | 走行台車／未選定 |
| 未確定送料・税・決済換算 | 走行台車／未選定 |
| 加工工具・作業費・残る自加工品の外注費 | 走行台車／未選定 |
| PLA仮合わせモックの材料消費 | 製作補助／未選定 |
| 荷物容器・敷板 | 積載物／未選定 |
| Picoケース固定用M3締結材 | 必要数確定・価格未計上 |

[E3設計と組立手順](../pico-control/README.ja.md) ／ [重量・強度の比較計算](PAYLOAD_REVIEW.ja.md)

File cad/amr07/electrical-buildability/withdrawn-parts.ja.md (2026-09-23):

# 撤回した電装部品の価格履歴

2026-09-23、回路製作設備なしの条件により、以下を現行購入BOMから外した。
表の価格・数量は旧候補の記録であり、購入指示ではない。代替品は未計上で、節約額を示さない。

[製作条件と確認した候補](README.ja.md) ／ [履歴CSV](withdrawn-parts.csv) ／ [現行BOM](../fixed-deck/BOM.ja.md)

| 旧ID | 旧候補 | 旧明細価格 | 外した理由 |
|---|---|---:|---|
| ELEC_S1 | IDEC XA1E-BV302R／2NC、φ16.2mm取付 | 3,153円 | はんだ端子。加工済み品／代替型番を未選定 |
| ELEC_K1_K2 | Omron G5LE-1 DC5／DC5Vコイル、NO接点を2個直列 | 770円 | 未設計の専用回路への実装が前提 |
| ELEC_U2 | CD74HC123E／再トリガ型ハートビート監視 | 140円 | 未設計の専用回路への実装が前提 |
| ELEC_U3 | TC74HC74AP／ARM押下エッジで許可 | 33円 | 未設計の専用回路への実装が前提 |
| ELEC_PS1 | M78AR05-1／5V 1A、主計算機用とは別 | 850円 | 未設計の専用回路への実装が前提 |
| ELEC_U4 | MAX3485ED (HTC)／3.3V、IC単体 | 70円 | 未設計の専用回路への実装が前提 |
| ELEC_RDUMP | ARCOL HS50 22R J／22Ω 50W、放熱条件付き | 1,033円 | 未設計の専用回路への実装が前提 |
| ELEC_U5 | LM393GN／バス過電圧検出 | 30円 | 未設計の専用回路への実装が前提 |
| ELEC_U6 | TL431A (HTC)／基準2.495V、調整必要 | 20円 | 未設計の専用回路への実装が前提 |
| ELEC_QCLAMP | 2SK2232／抵抗のON/OFFスイッチ | 100円 | 未設計の専用回路への実装が前提 |
| ELEC_PS2 | LM78L12／12V、モーターバスから給電 | 20円 | 未設計の専用回路への実装が前提 |
| ELEC_D0 | SBM1060LSS／60V 10A、10個入り | 300円 | 未設計の専用回路への実装が前提 |

旧価格合計：6,519円。価格確認日・URL・購入パックは履歴CSVに保持。

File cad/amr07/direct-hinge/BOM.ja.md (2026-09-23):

# D6.8 BOM

**途中小計 114,200円相当＋未計上分**。原通貨：85,203円＋184.38 USD。

[全明細Markdown](BOM-details.ja.md) ／ [CSV](BOM.csv) ／ [加工見積の証拠](MACHINING_QUOTE.ja.md)

円換算は記録済みの2026-09-21参考値1 USD＝157.2672円。現在の決済額ではありません。購入パック全額を計上し、余りを按分していません。PC・その電源・専用基板・配線などは未計上、モーター14,000円は仮予算、PLAは材料消費の参考です。

旧D6.7との差は約11,318円増。開き止め・ヒンジ用PLAは廃止。新しいL金具2個の実自動見積は63.38 USD、合計価格へ反映しています。

| 部位 | 円換算参考 | 割合 |
|---|---:|---:|
| 電池・充電器・アダプター | 23,380円 | 20.5% |
| 天板・ヒンジ・ロック | 20,774円 | 18.2% |
| フレーム・締結材・共通送料 | 20,000円 | 17.5% |
| モーター | 14,000円 | 12.3% |
| モーター専用金具 | 12,935円 | 11.3% |
| タイヤ・キャスター | 10,413円 | 9.1% |
| 制御・電源 | 9,443円 | 8.3% |
| PLA・ベルト | 3,255円 | 2.9% |

Amazonを優先。HG-TP20は1個1,309円、M4溝ナットは10個906円、M4×10は52本661円を確認。Prime会員としての最終配送条件は未確認です。その他の価格は各明細に確認日と仮枠の区別を残しています。

## 電池・充電器・アダプター

| 部品 | 使用／購入 | 原通貨金額 |
|---|---|---:|
| [純正電池＋急速充電器](BOM-details.ja.md#item-power_kit) | 1／1 式 | 19800 JPY |
| [電池・充電器セット送料](BOM-details.ja.md#item-power_kit_ship) | 1／1 式 | 600 JPY |
| [電池出力アダプター](BOM-details.ja.md#item-power_adapter) | 1／1 式 | 2180 JPY |
| [アダプター送料](BOM-details.ja.md#item-power_adapter_ship) | 1／1 式 | 800 JPY |

## 天板・ヒンジ・ロック

| 部品 | 使用／購入 | 原通貨金額 |
|---|---|---:|
| [D6.8格子穴アルミ天板](BOM-details.ja.md#item-deck_plate) | 1／1 枚 | 28.67 USD |
| [天板＋ヒンジL金具 日本宛共通送料](BOM-details.ja.md#item-deck_cnc_ship) | 1／未定 個 | 10.08 USD |
| [トルクヒンジ](BOM-details.ja.md#item-hatch_hinges) | 2／2 個 | 2618 JPY |
| [天板ロック用M6蝶ボルト](BOM-details.ja.md#item-hatch_locks) | 2／18 個 | 527 JPY |
| [天板ヒンジ用金属L金具](BOM-details.ja.md#item-hatch_metal_angles) | 2／2 個 | 63.38 USD |
| [3030用M4溝ナット](BOM-details.ja.md#item-hatch_frame_m4_nut) | 4／10 個 | 906 JPY |
| [固定葉用M4×10ボルト](BOM-details.ja.md#item-hatch_frame_m4_bolt) | 4／52 個 | 661 JPY |

## フレーム・締結材・共通送料

| 部品 | 使用／購入 | 原通貨金額 |
|---|---|---:|
| [3030フレーム 400mm](BOM-details.ja.md#item-f01) | 4／4 本 | 1952 JPY |
| [3030フレーム 300mm](BOM-details.ja.md#item-f02) | 4／4 本 | 1467 JPY |
| [基礎部の追加ねじ・ナット・座金](BOM-details.ja.md#item-h01) | 1／未定 式 | 2300 JPY |
| [モーター座面用小径平座金](BOM-details.ja.md#item-mw) | 6／10 枚 | 319.0 JPY |
| [フレーム・残存素材の追加送料枠](BOM-details.ja.md#item-s03) | 1／未定 式 | 1000 JPY |
| [純正接合部・溝ナットの送料枠](BOM-details.ja.md#item-s04) | 1／未定 式 | 未計上 |
| [Taobao送料・輸入諸費](BOM-details.ja.md#item-s07) | 1／未定 式 | 未計上 |
| [純正反転ブラケット本体](BOM-details.ja.md#item-f03) | 20／20 個 | 1834 JPY |
| [車体全体の先入れ溝ナット](BOM-details.ja.md#item-f04) | 66／100 個 | 5112 JPY |
| [ブラケット・天板固定ボルト](BOM-details.ja.md#item-d3_m6) | 44／70 個 | 2360 JPY |
| [印刷ストッパ固定ねじ](BOM-details.ja.md#item-d3_stop_bolts) | 8／未定 個 | 未計上 |
| [ストッパ・床継ぎ目用ナット](BOM-details.ja.md#item-d3_stop_nuts) | 36／40 個 | 546 JPY |
| [ストッパ用座金](BOM-details.ja.md#item-d3_stop_washers) | 8／未定 枚 | 未計上 |
| [荷物固定ベルト送料参考](BOM-details.ja.md#item-d3_strap_ship) | 1／未定 個 | 600 JPY |
| [100mm溝付き支柱4本](BOM-details.ja.md#item-d6_posts) | 4／4 本 | 495 JPY |
| [床・ケース・ヒンジ金具のM4×16](BOM-details.ja.md#item-d62_floor_screws) | 28／60 個 | 770 JPY |
| [継ぎ目支持梁端の大径平座金](BOM-details.ja.md#item-d62_beam_washers) | 4／未定 個 | 未計上 |
| [床・ケース・ヒンジのM4 OD12×t1座金](BOM-details.ja.md#item-d64_floor_washers) | 36／40 枚 | 860 JPY |
| [中央ねじ・座金の別店舗送料](BOM-details.ja.md#item-d64_fastener_ship) | 1／1 式 | 385 JPY |

## モーター

| 部品 | 使用／購入 | 原通貨金額 |
|---|---|---:|
| [ダイレクトドライブモーター](BOM-details.ja.md#item-d01) | 2／2 個 | 14000 JPY |

## モーター専用金具

| 部品 | 使用／購入 | 原通貨金額 |
|---|---|---:|
| [A6-R1専用モーター金具](BOM-details.ja.md#item-q01) | 2／2 個 | 75.02 USD |
| [CNC日本宛送料](BOM-details.ja.md#item-s08) | 1／未定 式 | 7.23 USD |

## タイヤ・キャスター

| 部品 | 使用／購入 | 原通貨金額 |
|---|---|---:|
| [タイヤ・カバーキット](BOM-details.ja.md#item-d02) | 2／2 キット | 9240 JPY |
| [自在キャスター](BOM-details.ja.md#item-c01) | 1／1 個 | 273 JPY |
| [キャスター取付板の素材](BOM-details.ja.md#item-p01) | 1／未定 枚 | 900 JPY |
| [キャスター送料](BOM-details.ja.md#item-s02) | 1／未定 式 | 0 JPY |
| [タイヤ国内通常送料](BOM-details.ja.md#item-s06) | 1／未定 式 | 0 JPY |

## 制御・電源

| 部品 | 使用／購入 | 原通貨金額 |
|---|---|---:|
| [Pico接続用USBデータケーブル](BOM-details.ja.md#item-e02) | 1／未定 本 | 500 JPY |
| [非常停止スイッチ](BOM-details.ja.md#item-elec_s1) | 1／1 個 | 3153 JPY |
| [駆動電源遮断リレー](BOM-details.ja.md#item-elec_k1_k2) | 2／2 個 | 770 JPY |
| [手持ちRaspberry Pi Pico](BOM-details.ja.md#item-elec_u1) | 1／0 個 | 0 JPY |
| [外部ウォッチドッグIC](BOM-details.ja.md#item-elec_u2) | 1／1 個 | 140 JPY |
| [手動再始動ラッチIC](BOM-details.ja.md#item-elec_u3) | 1／1 個 | 33 JPY |
| [監視回路用DC/DC](BOM-details.ja.md#item-elec_ps1) | 1／1 個 | 850 JPY |
| [RS485トランシーバIC](BOM-details.ja.md#item-elec_u4) | 1／1 個 | 70 JPY |
| [回生吸収抵抗](BOM-details.ja.md#item-elec_rdump) | 1／1 個 | 1033 JPY |
| [クランプ比較器](BOM-details.ja.md#item-elec_u5) | 1／1 個 | 30 JPY |
| [クランプ基準電圧IC](BOM-details.ja.md#item-elec_u6) | 1／1 個 | 20 JPY |
| [クランプMOSFET](BOM-details.ja.md#item-elec_qclamp) | 1／1 個 | 100 JPY |
| [クランプ制御用レギュレータ](BOM-details.ja.md#item-elec_ps2) | 1／1 個 | 20 JPY |
| [電池への逆流防止ダイオード](BOM-details.ja.md#item-elec_d0) | 1／10 個 | 300 JPY |
| [手動ARMボタン（黒）](BOM-details.ja.md#item-elec_arm) | 1／1 個 | 835 JPY |
| [全電源の主スイッチ](BOM-details.ja.md#item-elec_main) | 1／1 個 | 621 JPY |
| [天板ロック用M6 OD18×t1座金](BOM-details.ja.md#item-elec_case_washer) | 6／30 個 | 968 JPY |

## PLA・ベルト

| 部品 | 使用／購入 | 原通貨金額 |
|---|---|---:|
| [床・PCカバー・荷物止め・操作ケース](BOM-details.ja.md#item-p04) | 888／0 g | 1776 JPY |
| [電池モジュール保持ベルト](BOM-details.ja.md#item-h02) | 1／1 本 | 393 JPY |
| [荷物固定ベルト](BOM-details.ja.md#item-deck_cargo_straps) | 2／2 本 | 786 JPY |
| [ベルト接触部の保護材・余長固定](BOM-details.ja.md#item-deck_edge_protection_and_slack_retention) | 1／未定 式 | 300 JPY |
| [電池・電装の軟質当て材](BOM-details.ja.md#item-power_pads) | 1／1 式 | 未計上 |
| [1階計算機・監視回路の保持ベルト](BOM-details.ja.md#item-power_low_straps) | 2／未定 本 | 未計上 |

## 未計上品

| 部品 | 状態 |
|---|---|
| 純正接合部・溝ナットの送料枠 | 送料未確定 |
| Taobao送料・輸入諸費 | 未見積 |
| 印刷ストッパ固定ねじ | 寸法選定済・実機検証前 |
| ストッパ用座金 | 寸法選定済・実機検証前 |
| 電池・電装の軟質当て材 | 型式選定・現物／電気検証前 |
| 1階計算機・監視回路の保持ベルト | 型式選定・現物／電気検証前 |
| 継ぎ目支持梁端の大径平座金 | 寸法選定済・購入パック未確定 |
| 独立した電池低電圧保護回路 | 走行台車／未選定 |
| 上位計算機・記憶媒体・冷却 | 走行台車／未選定 |
| 上位計算機用DC/DC | 走行台車／未選定 |
| 電源着脱コネクタ・ヒューズ等の配電部品 | 走行台車／未選定 |
| ヒューズ・ホルダー | 走行台車／未選定 |
| 制御・分配基板とコネクタ | 走行台車／未選定 |
| リレーコイル駆動・保護部品 | 走行台車／未選定 |
| レベル変換・デバウンス・電源投入リセット | 走行台車／未選定 |
| 抵抗・コンデンサ・終端抵抗 | 走行台車／未選定 |
| 電圧・電流計測部品 | 走行台車／未選定 |
| 電源線・信号線・圧着端子・結束材 | 走行台車／未選定 |
| 放熱固定具・ガード・絶縁材 | 走行台車／未選定 |
| 電装固定板・ケース・スタンドオフ | 走行台車／未選定 |
| 未確定送料・税・決済換算 | 走行台車／未選定 |
| 加工工具・作業費・残る自加工品の外注費 | 走行台車／未選定 |
| PLA仮合わせモックの材料消費 | 製作補助／未選定 |
| 自律移動用LiDAR・IMU・カメラ等 | 将来自律移動／未選定 |
| 荷物容器・敷板 | 積載物／未選定 |

[設計と組立手順](README.ja.md) ／ [重量・強度の比較計算](PAYLOAD_REVIEW.ja.md)

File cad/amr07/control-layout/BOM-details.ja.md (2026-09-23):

# D6.6 BOM：全明細

**[費用概要・購入リスト](BOM.ja.md) ／ [同じ内容のCSV](BOM.csv)**

CSVの全74明細・19項目を掲載。スマートフォンでも読めるよう、1品目ごとの「項目／内容」の表にしている。

「—」はCSVの空欄。未確定・未計上を0円や0個と扱わない。数量の単位と価格の通貨はそれぞれの行を参照。価格は記録済みの値で、確認条件は「価格根拠」「選定状況」「備考」に記載している。

## 部位から探す

- [電池・充電器・アダプター](#category-1)
- [フレーム・締結材](#category-2)
- [モーター2個](#category-3)
- [専用モーター金具2個](#category-4)
- [タイヤ・キャスター](#category-5)
- [制御・電源保護](#category-6)
- [アルミ天板](#category-7)
- [PLA・ベルト・保護材](#category-8)
- [その他送料](#category-9)
- [未選定・未計上品](#category-10)

## 電池・充電器・アダプター

### POWER\_KIT — 純正電池＋急速充電器

| 項目 | 内容 |
|---|---|
| ID | POWER\_KIT |
| 分類 | D5選定電源 |
| 部品名 | 純正電池＋急速充電器 |
| 仕様・型番 | Makita BL1860B A-60464 x1 + DC18RF JPADC18RF x1 |
| 使用数 | 1 |
| 単位 | 式 |
| 購入予定数 | 1 |
| 購入単位 | 1式 |
| 購入口数 | 1 |
| 余剰数 | 0 |
| 購入単位単価 | 19800 |
| 明細金額 | 19800 |
| 通貨 | JPY |
| 価格根拠 | 2026-09-22 販売ページ表示 |
| 選定状況 | 型式選定・現物／電気検証前 |
| 購入先 | — |
| URL | [購入先・根拠ページ](https://store.shopping.yahoo.co.jp/takahashihonsha/0088381464031-0088381523394-s.html) |
| CAD形状数 | — |
| 備考 | どちらも未所有のため新規購入。新品セットばらし・化粧箱なし。充電器は車外。電池単体を別行で二重計上しない。 |

[費用概要へ戻る](BOM.ja.md) ／ [部位一覧へ戻る](#部位から探す)

### POWER\_KIT\_SHIP — 電池・充電器セット送料

| 項目 | 内容 |
|---|---|
| ID | POWER\_KIT\_SHIP |
| 分類 | D5選定電源 |
| 部品名 | 電池・充電器セット送料 |
| 仕様・型番 | 東京都表示送料 |
| 使用数 | 1 |
| 単位 | 式 |
| 購入予定数 | 1 |
| 購入単位 | 1式 |
| 購入口数 | 1 |
| 余剰数 | 0 |
| 購入単位単価 | 600 |
| 明細金額 | 600 |
| 通貨 | JPY |
| 価格根拠 | 2026-09-22 販売ページ表示 |
| 選定状況 | 型式選定・現物／電気検証前 |
| 購入先 | — |
| URL | [購入先・根拠ページ](https://store.shopping.yahoo.co.jp/takahashihonsha/0088381464031-0088381523394-s.html) |
| CAD形状数 | — |
| 備考 | 住所・注文条件により変動。ポイントは値引き計上しない。 |

[費用概要へ戻る](BOM.ja.md) ／ [部位一覧へ戻る](#部位から探す)

### POWER\_ADAPTER — 電池出力アダプター

| 項目 | 内容 |
|---|---|
| ID | POWER\_ADAPTER |
| 分類 | D5選定電源 |
| 部品名 | 電池出力アダプター |
| 仕様・型番 | Netkey diy-adapter03、14AWG、スイッチ・30Aヒューズ付き |
| 使用数 | 1 |
| 単位 | 式 |
| 購入予定数 | 1 |
| 購入単位 | 1式 |
| 購入口数 | 1 |
| 余剰数 | 0 |
| 購入単位単価 | 2180 |
| 明細金額 | 2180 |
| 通貨 | JPY |
| 価格根拠 | 2026-09-22 販売ページ表示 |
| 選定状況 | 型式選定・現物／電気検証前 |
| 購入先 | — |
| URL | [購入先・根拠ページ](https://store.shopping.yahoo.co.jp/netkey-store/diy-adapter03.html) |
| CAD形状数 | — |
| 備考 | 公称約95×90×30mm・123g。全高30mmを加算。低電圧保護には使わない。付属30Aのまま小ハーネス保護を保証しない。 |

[費用概要へ戻る](BOM.ja.md) ／ [部位一覧へ戻る](#部位から探す)

### POWER\_ADAPTER\_SHIP — アダプター送料

| 項目 | 内容 |
|---|---|
| ID | POWER\_ADAPTER\_SHIP |
| 分類 | D5選定電源 |
| 部品名 | アダプター送料 |
| 仕様・型番 | 東京都表示送料 |
| 使用数 | 1 |
| 単位 | 式 |
| 購入予定数 | 1 |
| 購入単位 | 1式 |
| 購入口数 | 1 |
| 余剰数 | 0 |
| 購入単位単価 | 800 |
| 明細金額 | 800 |
| 通貨 | JPY |
| 価格根拠 | 2026-09-22 販売ページ表示 |
| 選定状況 | 型式選定・現物／電気検証前 |
| 購入先 | — |
| URL | [購入先・根拠ページ](https://store.shopping.yahoo.co.jp/netkey-store/diy-adapter03.html) |
| CAD形状数 | — |
| 備考 | 発送予定のある商品。ユーザー住所と最終納期は未確認。 |

[費用概要へ戻る](BOM.ja.md) ／ [部位一覧へ戻る](#部位から探す)

## フレーム・締結材

### F01 — 3030フレーム 400mm

| 項目 | 内容 |
|---|---|
| ID | F01 |
| 分類 | フレーム |
| 部品名 | 3030フレーム 400mm |
| 仕様・型番 | MISUMI NFSL6-3030-400 |
| 使用数 | 4 |
| 単位 | 本 |
| 購入予定数 | 4 |
| 購入単位 | 4本組×1 |
| 購入口数 | 1 |
| 余剰数 | 0 |
| 購入単位単価 | 1952.0 |
| 明細金額 | 1952 |
| 通貨 | JPY |
| 価格根拠 | 過去価格の引継ぎ |
| 選定状況 | 型式選定済・価格引継ぎ |
| 購入先 | Amazon |
| URL | [購入先・根拠ページ](https://www.amazon.co.jp/dp/B0DKF2CCW3) |
| CAD形状数 | 4 |
| 備考 | Amazonの現価格は再取得できず。余り0本。 |

[費用概要へ戻る](BOM.ja.md) ／ [部位一覧へ戻る](#部位から探す)

### F02 — 3030フレーム 300mm

| 項目 | 内容 |
|---|---|
| ID | F02 |
| 分類 | フレーム |
| 部品名 | 3030フレーム 300mm |
| 仕様・型番 | MISUMI NFSL6-3030-300 |
| 使用数 | 4 |
| 単位 | 本 |
| 購入予定数 | 4 |
| 購入単位 | 4本組×1 |
| 購入口数 | 1 |
| 余剰数 | 0 |
| 購入単位単価 | 1467.0 |
| 明細金額 | 1467 |
| 通貨 | JPY |
| 価格根拠 | 過去価格の引継ぎ |
| 選定状況 | 型式選定済・価格引継ぎ |
| 購入先 | Amazon |
| URL | [購入先・根拠ページ](https://www.amazon.co.jp/dp/B0DKDZ8G9G) |
| CAD形状数 | 4 |
| 備考 | 下段2本＋上段2本。購入予定4本セットを全て使用し、D5から追加購入なし。価格1467円は同日P1/D5の観測を継承。 |

[費用概要へ戻る](BOM.ja.md) ／ [部位一覧へ戻る](#部位から探す)

### D6\_POSTS — 100mm溝付き支柱4本

| 項目 | 内容 |
|---|---|
| ID | D6\_POSTS |
| 分類 | D6 上段支持 |
| 部品名 | 100mm溝付き支柱4本 |
| 仕様・型番 | SUS SF2-30・30 BLACK／SF9-322、100mm×4本 |
| 使用数 | 4 |
| 単位 | 本 |
| 購入予定数 | 4 |
| 購入単位 | 4本/パック |
| 購入口数 | 1 |
| 余剰数 | 0 |
| 購入単位単価 | 495 |
| 明細金額 | 495 |
| 通貨 | JPY |
| 価格根拠 | 2026-09-22 Amazon商品ページ表示 |
| 選定状況 | 型式・メーカー断面CAD確認、金具混用の現物確認前 |
| 購入先 | Amazon掲載 |
| URL | [購入先・根拠ページ](https://www.amazon.co.jp/dp/B0CB5N6ZJJ) |
| CAD形状数 | 4 |
| 備考 | ブラック100mm4本を選択。メーカー単位質量0.84kg/m。切断・端面タップ・追加穴加工なし。通常5～6日以内発送の表示、送料・Prime配送は未確認。 |

[費用概要へ戻る](BOM.ja.md) ／ [部位一覧へ戻る](#部位から探す)

### F03 — 純正反転ブラケット本体

| 項目 | 内容 |
|---|---|
| ID | F03 |
| 分類 | D3荷台・フレーム |
| 部品名 | 純正反転ブラケット本体 |
| 仕様・型番 | HBLFSN6 |
| 使用数 | 20 |
| 単位 | 個 |
| 購入予定数 | 20 |
| 購入単位 | 10個/パック |
| 購入口数 | 2 |
| 余剰数 | 0 |
| 購入単位単価 | 917 |
| 明細金額 | 1834 |
| 通貨 | JPY |
| 価格根拠 | 2026-09-22 P1商品確認を継承 |
| 選定状況 | 寸法選定済・実機検証前 |
| 購入先 | Amazon掲載 |
| URL | [購入先・根拠ページ](https://www.amazon.co.jp/dp/B0DKF1FCD6) |
| CAD形状数 | 20 |
| 備考 | 基礎8個＋支柱下端8個＋上端4個。D6.1の根元両側固定は購入予定パックの余り4個で対応。917円/パックは同日P1/D5の観測を継承。SUS支柱との混用は公称断面適合、現物の突起・座面確認が必要。 |

[費用概要へ戻る](BOM.ja.md) ／ [部位一覧へ戻る](#部位から探す)

### F04 — 車体全体の先入れ溝ナット

| 項目 | 内容 |
|---|---|
| ID | F04 |
| 分類 | D3荷台・フレーム |
| 部品名 | 車体全体の先入れ溝ナット |
| 仕様・型番 | HNTT6-6 |
| 使用数 | 78 |
| 単位 | 個 |
| 購入予定数 | 100 |
| 購入単位 | 50個/パック |
| 購入口数 | 2 |
| 余剰数 | 22 |
| 購入単位単価 | 2556 |
| 明細金額 | 5112 |
| 通貨 | JPY |
| 価格根拠 | 2026-09-22 商品ページ2556円/50個を再確認 |
| 選定状況 | 寸法選定済・実機検証前 |
| 購入先 | Amazon掲載 |
| URL | [購入先・根拠ページ](https://www.amazon.co.jp/dp/B0DK9C99YH) |
| CAD形状数 | 78 |
| 備考 | D6.5の70個＋後方ケース8個。購入予定100個の内数。手持ちとは扱わない。 |

[費用概要へ戻る](BOM.ja.md) ／ [部位一覧へ戻る](#部位から探す)

### H01 — 基礎部の追加ねじ・ナット・座金

| 項目 | 内容 |
|---|---|
| ID | H01 |
| 分類 | 締結材 |
| 部品名 | 基礎部の追加ねじ・ナット・座金 |
| 仕様・型番 | 詳細は締結部品表、基礎部50点 |
| 使用数 | 1 |
| 単位 | 式 |
| 購入予定数 | — |
| 購入単位 | 個別パック未確定 |
| 購入口数 | — |
| 余剰数 | — |
| 購入単位単価 | — |
| 明細金額 | 2300 |
| 通貨 | JPY |
| 価格根拠 | 予算枠 |
| 選定状況 | 数量確定・購入単位未確定 |
| 購入先 | — |
| URL | — |
| CAD形状数 | 50 |
| 備考 | 従来66点から三角板用M6ねじ8本・座金8枚を削除。溝ナット8個の削除はF04。2300円の一式仮枠は購入パック未確定のため据置き、16点の削減を架空の節約額へ換算しない。モーターねじFC-2512候補を含む。 |

[費用概要へ戻る](BOM.ja.md) ／ [部位一覧へ戻る](#部位から探す)

### MW — モーター座面用小径平座金

| 項目 | 内容 |
|---|---|
| ID | MW |
| 分類 | 締結材 |
| 部品名 | モーター座面用小径平座金 |
| 仕様・型番 | WILCO FW-2505-05EB、2.7×5×0.5mm |
| 使用数 | 6 |
| 単位 | 枚 |
| 購入予定数 | 10 |
| 購入単位 | 10枚一括購入（数量割引） |
| 購入口数 | 1 |
| 余剰数 | 4 |
| 購入単位単価 | 319.0 |
| 明細金額 | 319.0 |
| 通貨 | JPY |
| 価格根拠 | 販売表示・条件付き |
| 選定状況 | 型式選定済 |
| 購入先 | WILCO |
| URL | [購入先・根拠ページ](https://wilco.jp/products/F/FW-EB.html) |
| CAD形状数 | 6 |
| 備考 | 10枚以上29円/枚は税別。10枚税込319円、予備4枚。最低注文数が10枚という意味ではない。 |

[費用概要へ戻る](BOM.ja.md) ／ [部位一覧へ戻る](#部位から探す)

### D3\_M6 — ブラケット・天板固定ボルト

| 項目 | 内容 |
|---|---|
| ID | D3\_M6 |
| 分類 | D3荷台・フレーム |
| 部品名 | ブラケット・天板固定ボルト |
| 仕様・型番 | M6x12 六角穴付、CBM6-12相当 |
| 使用数 | 58 |
| 単位 | 個 |
| 購入予定数 | 70 |
| 購入単位 | 35本/パック |
| 購入口数 | 2 |
| 余剰数 | 12 |
| 購入単位単価 | 1180 |
| 明細金額 | 2360 |
| 通貨 | JPY |
| 価格根拠 | 2026-09-23 Amazon商品ページ、35本1180円税込 |
| 選定状況 | Onokatsu131-00-M6x12、購入パック確定・未購入 |
| 購入先 | オノカツ／Amazon発送 |
| URL | [購入先・根拠ページ](https://www.amazon.co.jp/dp/B01N3BIIMO) |
| CAD形状数 | — |
| 備考 | D6.5別枠50本＋操作部8本＝58本。旧50本も未計上だったため2360円全てを今回初計上。基礎H01内の別枠4本には割り当てず、パック余剰12本として保持。一式H01は個別買付表へ分解するまで予算枠を据置く。 |

[費用概要へ戻る](BOM.ja.md) ／ [部位一覧へ戻る](#部位から探す)

### D3\_STOP\_BOLTS — 印刷ストッパ固定ねじ

| 項目 | 内容 |
|---|---|
| ID | D3\_STOP\_BOLTS |
| 分類 | D3荷台・フレーム |
| 部品名 | 印刷ストッパ固定ねじ |
| 仕様・型番 | M4x25 六角穴付 |
| 使用数 | 8 |
| 単位 | 個 |
| 購入予定数 | — |
| 購入単位 | — |
| 購入口数 | — |
| 余剰数 | — |
| 購入単位単価 | — |
| 明細金額 | — |
| 通貨 | JPY |
| 価格根拠 | 購入単価未確定 |
| 選定状況 | 寸法選定済・実機検証前 |
| 購入先 | — |
| URL | — |
| CAD形状数 | — |
| 備考 | PLA位置決め部品40x15x15を一個2本で固定。主荷物保持はベルト。 |

[費用概要へ戻る](BOM.ja.md) ／ [部位一覧へ戻る](#部位から探す)

### D3\_STOP\_NUTS — ストッパ・床継ぎ目用ナット

| 項目 | 内容 |
|---|---|
| ID | D3\_STOP\_NUTS |
| 分類 | D3荷台・フレーム |
| 部品名 | ストッパ・床継ぎ目用ナット |
| 仕様・型番 | TRUSCO Y810-0004、M4×0.7、三価クロメート、対辺7mmの公称モデル |
| 使用数 | 20 |
| 単位 | 個 |
| 購入予定数 | 20 |
| 購入単位 | 20個/パック |
| 購入口数 | 1 |
| 余剰数 | 0 |
| 購入単位単価 | 273 |
| 明細金額 | 273 |
| 通貨 | JPY |
| 価格根拠 | 2026-09-23 Amazon商品ページ、20個273円税込 |
| 選定状況 | パック確定・未購入 |
| 購入先 | Amazon.co.jp |
| URL | [購入先・根拠ページ](https://www.amazon.co.jp/dp/B0BVQJS1D2) |
| CAD形状数 | — |
| 備考 | ストッパ8＋床継ぎ目4＋ケース蓋8＝20。従来12個も未計上だったためパック全額を初計上。 |

[費用概要へ戻る](BOM.ja.md) ／ [部位一覧へ戻る](#部位から探す)

### D3\_STOP\_WASHERS — ストッパ用座金

| 項目 | 内容 |
|---|---|
| ID | D3\_STOP\_WASHERS |
| 分類 | D3荷台・フレーム |
| 部品名 | ストッパ用座金 |
| 仕様・型番 | M4 ID4.3～4.4 OD9 t0.8（荷物ストッパ用） |
| 使用数 | 8 |
| 単位 | 枚 |
| 購入予定数 | — |
| 購入単位 | — |
| 購入口数 | — |
| 余剰数 | — |
| 購入単位単価 | — |
| 明細金額 | — |
| 通貨 | JPY |
| 価格根拠 | 購入単価未確定 |
| 選定状況 | 寸法選定済・実機検証前 |
| 購入先 | — |
| URL | — |
| CAD形状数 | — |
| 備考 | 荷物ストッパ8枚。床継ぎ目のOD12座金8枚はD64\_FLOOR\_WASHERSへ分離。 |

[費用概要へ戻る](BOM.ja.md) ／ [部位一覧へ戻る](#部位から探す)

### D62\_FLOOR\_SCREWS — 床継ぎ目・操作ケース蓋のM4×16

| 項目 | 内容 |
|---|---|
| ID | D62\_FLOOR\_SCREWS |
| 分類 | D6.4 1階床支持 |
| 部品名 | 床継ぎ目・操作ケース蓋のM4×16 |
| 仕様・型番 | オノカツ133-00-0416、M4×16、JIS B1176、頭径7×高さ4mm |
| 使用数 | 12 |
| 単位 | 個 |
| 購入予定数 | 60 |
| 購入単位 | 60本/パック |
| 購入口数 | 1 |
| 余剰数 | 48 |
| 購入単位単価 | 770 |
| 明細金額 | 770 |
| 通貨 | JPY |
| 価格根拠 | 2026-09-23 メーカー直販ページ770円税込/60本 |
| 選定状況 | 汎用規格品の購入候補、未購入 |
| 購入先 | オノカツ公式ストア |
| URL | [購入先・根拠ページ](https://store.onokatsu.co.jp/products/133-00-04) |
| CAD形状数 | 12 |
| 備考 | 床継ぎ目4本＋操作ケース蓋8本。購入予定60本から流用、買い増しなし。直販770円＋共通送料385円を維持。 |

[費用概要へ戻る](BOM.ja.md) ／ [部位一覧へ戻る](#部位から探す)

### D62\_BEAM\_WASHERS — 継ぎ目支持梁端の大径平座金

| 項目 | 内容 |
|---|---|
| ID | D62\_BEAM\_WASHERS |
| 分類 | D6.2 1階床支持 |
| 部品名 | 継ぎ目支持梁端の大径平座金 |
| 仕様・型番 | M6 ID6.6 OD18 t1.6 |
| 使用数 | 4 |
| 単位 | 個 |
| 購入予定数 | — |
| 購入単位 | — |
| 購入口数 | — |
| 余剰数 | — |
| 購入単位単価 | — |
| 明細金額 | — |
| 通貨 | JPY |
| 価格根拠 | 購入単価未確定 |
| 選定状況 | 寸法選定済・購入パック未確定 |
| 購入先 | — |
| URL | — |
| CAD形状数 | 4 |
| 備考 | 汎用金属締結材。PLAへのタップではなく貫通締結。追加加工見積は不要。コーナン等の小袋を優先し、価格は未計上。 |

[費用概要へ戻る](BOM.ja.md) ／ [部位一覧へ戻る](#部位から探す)

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

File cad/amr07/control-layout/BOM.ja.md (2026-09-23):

# D6.6 BOM：費用の内訳と購入リスト

**[全明細をMarkdownで読む](BOM-details.ja.md) ／ [CSVを開く・保存する](BOM.csv)**

**途中小計 約98,694円 ＋ 未計上分**。通常積載目標10kg、車体推計10.409kg（10kgは目安）の現行構成。

**主計算機・その電源・配線／基板／ケース・追加ねじなどは未計上。LiDARやカメラ等の将来センサーも含まない。** 完成車の総額ではない。

## どこに費用がかかるか

| 部位 | 金額の目安 | 割合 |
|---|---:|---:|
| 電池・充電器・アダプター | 23,380円 | 23.7% |
| フレーム・締結材 | 17,312円 | 17.5% |
| モーター2個 | 14,000円 | 14.2% |
| 専用モーター金具2個 | 12,935円 | 13.1% |
| タイヤ・キャスター | 10,413円 | 10.6% |
| 制御・電源保護 | 9,443円 | 9.6% |
| アルミ天板 | 6,078円 | 6.2% |
| PLA・ベルト・保護材 | 3,147円 | 3.2% |
| その他送料 | 1,985円 | 2.0% |
| **途中小計** | **98,694円** | **100%** |
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

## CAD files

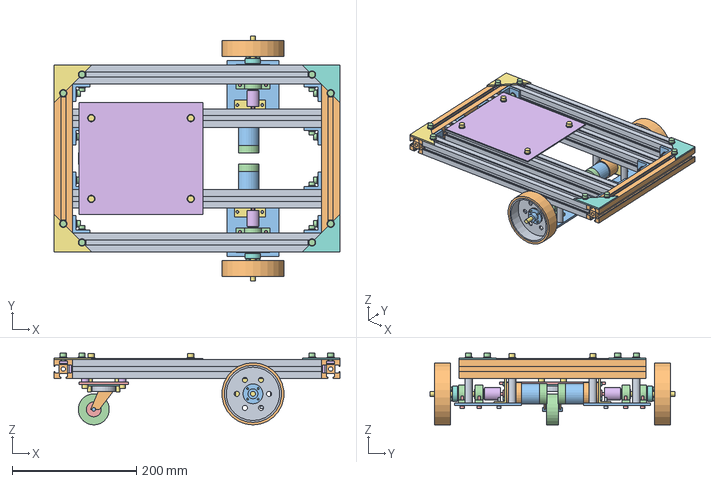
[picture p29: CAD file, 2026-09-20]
cad/amr01/AMR01_FirstDesign_A.step
460.0 x 394.0 x 115.6 mm

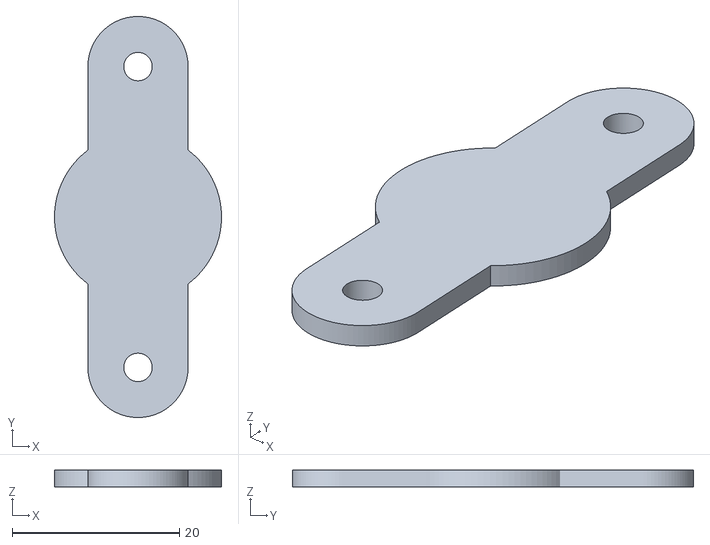
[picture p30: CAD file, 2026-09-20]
cad/amr02/ShaftEndCapL.stl
20.0 x 48.0 x 2.00

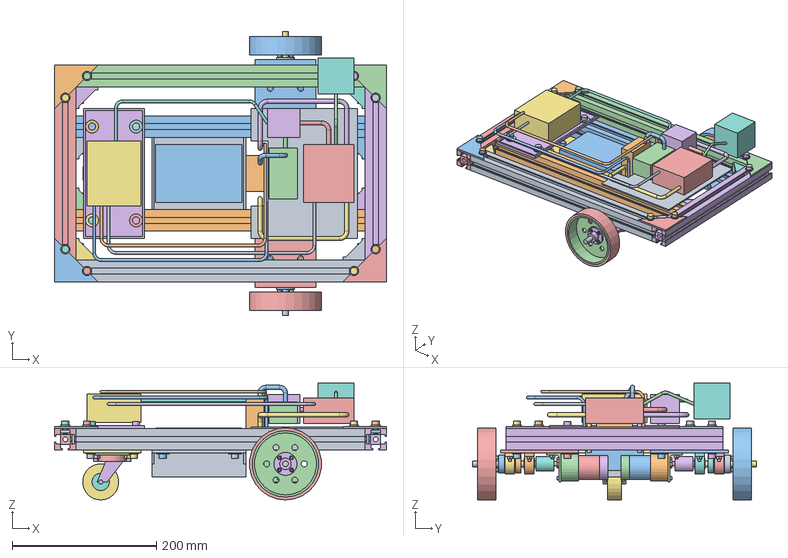
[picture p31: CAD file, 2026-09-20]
cad/amr03/AMR01_ElectricalLayout_A2.FCStd
460.0 x 394.0 x 162.0 mm
Rail400_1
Rail400_2
Rail400_3
Rail400_4
Cross300_1
Cross300_2
Bracket_NN120
JointA_NN120
SlotNut_JointA_NN120
JointB_NN120
SlotNut_JointB_NN120
Bracket_NN50
JointA_NN50
SlotNut_JointA_NN50
JointB_NN50
SlotNut_JointB_NN50
Bracket_N50
JointA_N50
SlotNut_JointA_N50
JointB_N50
SlotNut_JointB_N50
Bracket_N120
JointA_N120
SlotNut_JointA_N120
JointB_N120
SlotNut_JointB_N120
Gusset_N1N1
Washer_GussetN1N10
GussetBolt_N1N10
SlotNut_Gusset_N1N10
Washer_GussetN1N11
GussetBolt_N1N11
SlotNut_Gusset_N1N11
Gusset_N11
Washer_GussetN110
GussetBolt_N110
SlotNut_Gusset_N110
Washer_GussetN111
GussetBolt_N111
SlotNut_Gusset_N111
Bracket_PN120
JointA_PN120
SlotNut_JointA_PN120
JointB_PN120
SlotNut_JointB_PN120
Bracket_PN50
JointA_PN50
SlotNut_JointA_PN50
JointB_PN50
SlotNut_JointB_PN50
Bracket_P50
JointA_P50
SlotNut_JointA_P50
JointB_P50
SlotNut_JointB_P50
Bracket_P120
JointA_P120
SlotNut_JointA_P120
JointB_P120
SlotNut_JointB_P120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

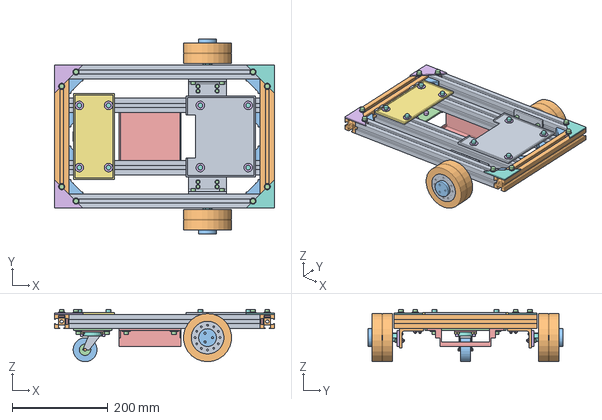
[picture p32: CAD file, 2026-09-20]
cad/amr04/AMR01_DDSM115_A3.step
460.0 x 407.0 x 109.6 mm

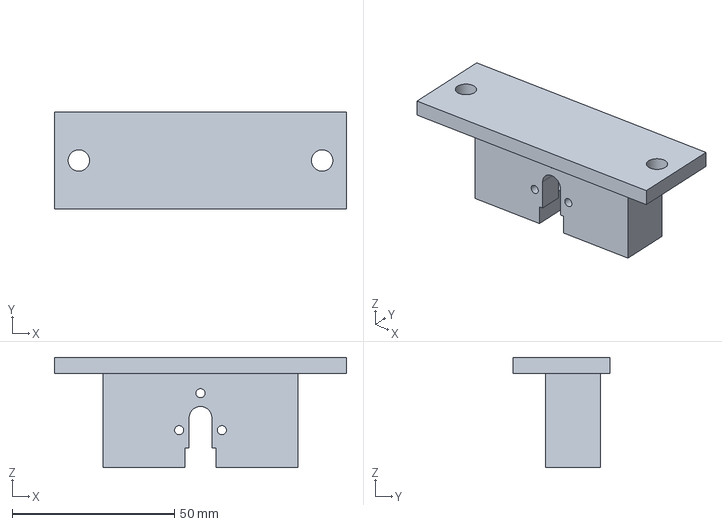
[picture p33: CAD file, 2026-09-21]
cad/amr05/M0601C_custom_mount_quote.step
90.0 x 30.0 x 34.0 mm

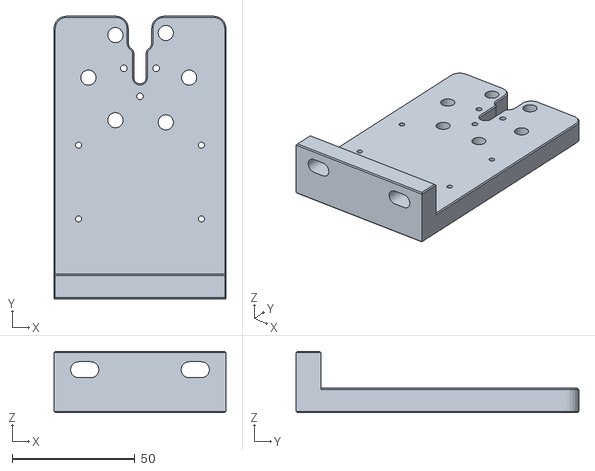
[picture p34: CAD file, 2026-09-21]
cad/amr05/reference/DDT-M0601C-BRACKET-source-display-mm.stl
70.0 x 115.0 x 25.0

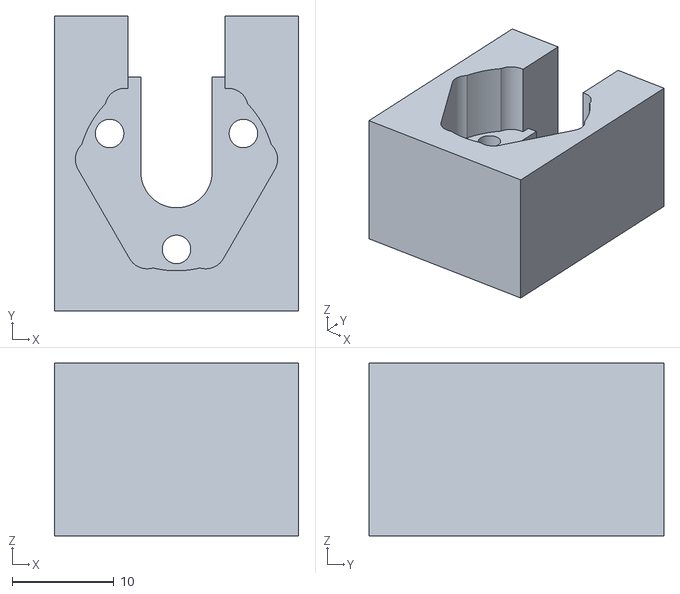
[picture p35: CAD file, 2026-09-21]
cad/amr06/print-mock/M0601C_seat_A5_fit_coupon.stl
24.0 x 29.0 x 17.0

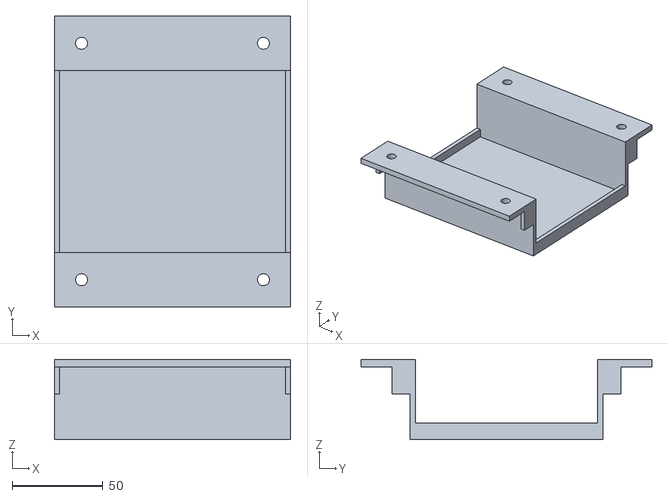
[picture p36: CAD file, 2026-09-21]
cad/amr07/aluminum-direct-deck/BatteryCradlePLA.stl
130.0 x 160.0 x 44.0

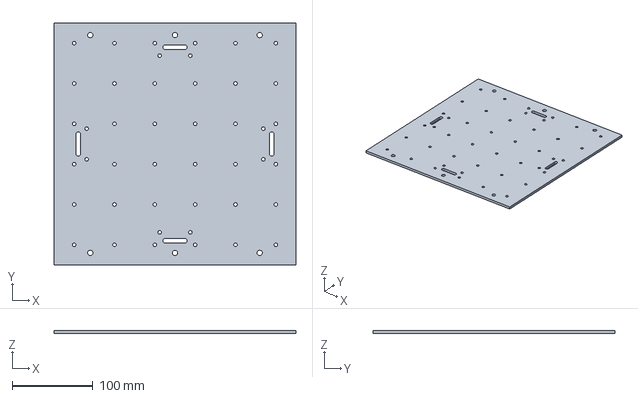
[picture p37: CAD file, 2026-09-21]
cad/amr07/aluminum-grid-deck/AMR_GridDeck_C45_D2.step
300.0 x 300.0 x 4.00 mm

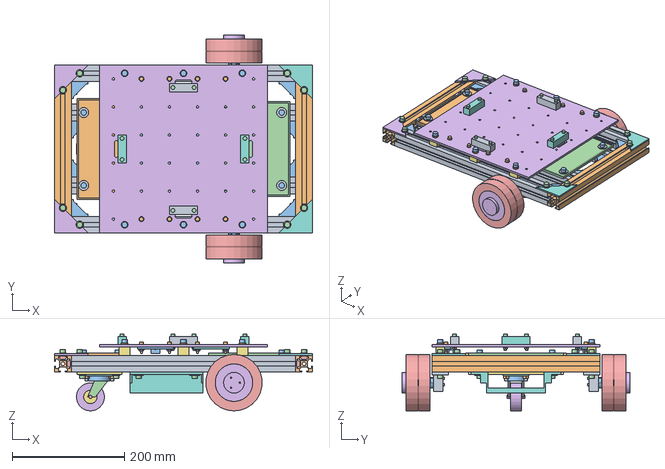
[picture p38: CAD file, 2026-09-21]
cad/amr07/AMR01_M0601C_A6.step
460.0 x 406.6 x 137.0 mm

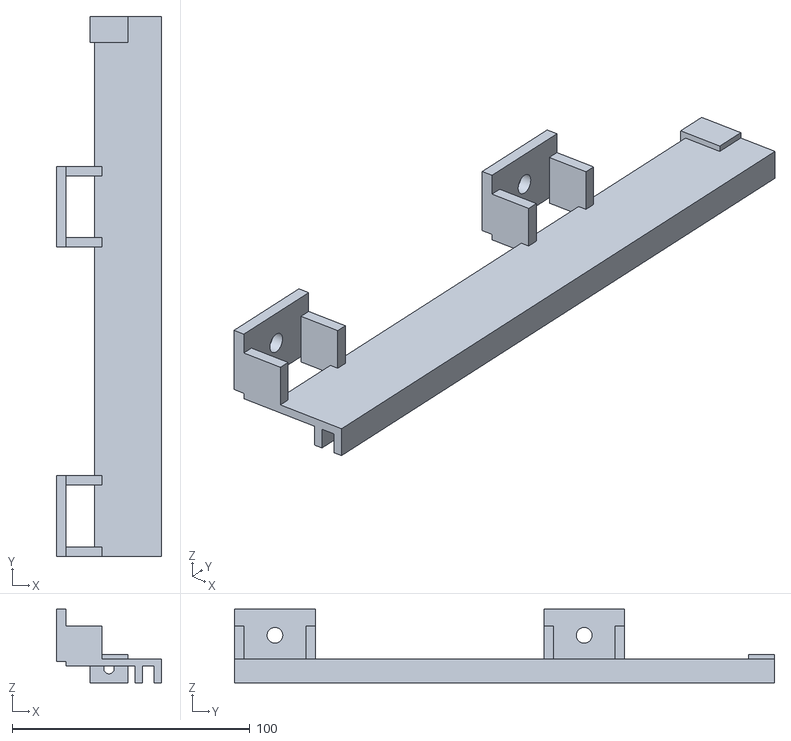
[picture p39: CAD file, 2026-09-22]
cad/amr07/battery-drawer/BatteryGuideXP.stl
44.0 x 227.0 x 31.0

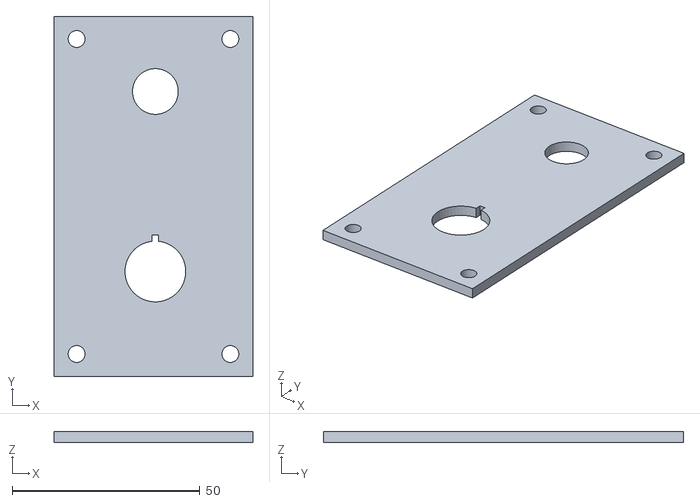
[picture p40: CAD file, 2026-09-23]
cad/amr07/control-layout/RearStopLidPLA.stl
53.0 x 96.0 x 3.00

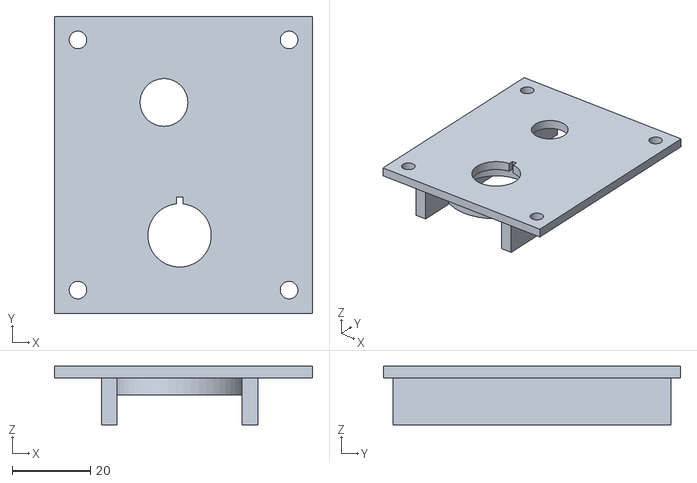
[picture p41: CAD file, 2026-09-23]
cad/amr07/direct-hinge/RearStopLidPLA.stl
66.0 x 76.0 x 15.0

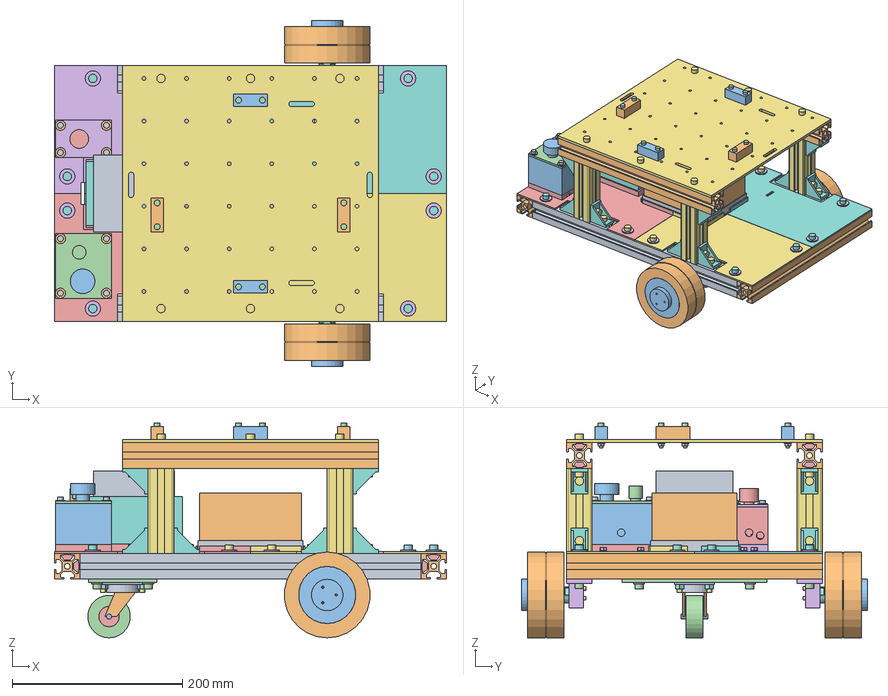
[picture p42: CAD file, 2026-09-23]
cad/amr07/fixed-deck/AMR01_FixedDeck_D69.step
460.0 x 406.6 x 252.0 mm

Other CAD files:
cad/amr06/AMR01_M0601C_A5.step
cad/amr06/candidates/M0601C_mount_D3_R2_LongRoots.step
cad/amr07/aluminum-grid-quote/AMR_GridDeck_C45_Q1.step
cad/amr07/direct-hinge/quote-input/AMR_GridDeck_D68C.step
cad/CenterHolePlate.FCStd
cad/CenterHolePlate.step
cad/amr01/AMR01_FirstDesign_A.FCStd
cad/amr02/AMR01_Option_C_TopMotor.FCStd
cad/amr02/AMR01_Option_C_TopMotor.step
cad/amr02/AMR01_SecondDesign_B.FCStd
cad/amr02/AMR01_SecondDesign_B.step
cad/amr02/EquipmentTrayPLA.stl
cad/amr03/AMR01_Revision_A2.FCStd
cad/amr03/AMR01_Revision_A2.step
cad/amr04/AMR01_DDSM115_A3.FCStd
cad/amr04/AMR01_ElectricalLayout_A3.FCStd
cad/amr05/AMR01_ElectricalLayout_A4.FCStd
cad/amr05/AMR01_M0601C_A4.FCStd
cad/amr05/AMR01_M0601C_A4.step
cad/amr05/AMR01_StockBracket_Fit_A4.FCStd
cad/amr05/BatteryCradlePLA.stl
cad/amr05/ElectronicsTrayPLA.stl
cad/amr05/FrontElectronicsTrayPLA.stl
cad/amr06/AMR01_M0601C_A5.FCStd
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

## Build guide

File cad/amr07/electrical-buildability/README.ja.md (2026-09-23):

# 最初に動かすための電装（E3）

**車載LinuxミニPC → USB → 手持ちPico → 完成済み2CH RS485基板 → 左右M0601C_111** を現行構成とする。まず手動で前後進・旋回・停止でき、非常停止でモーター電源を切れる構成を作る。自作PCB・裸ICからの回路組立・ユーザーのはんだ付けは前提にしない。

[配置・CAD画像](../pico-control/README.ja.md) ／ [配線構成](../pico-control/WIRING.ja.md) ／ [要件JSON](requirements.json) ／ [BOM](../fixed-deck/BOM.ja.md)

| 部品・機能 | 現行の扱いと用途 |
|---|---|
| 手持ちPico＋2CH RS485 HAT | USB指令を左右のUART–RS485へ渡す。専用ファームウェアは未実装 |
| 別体USB–RS485変換器 | Pico/HAT構成では購入しない |
| 外付けモータードライバー | M0601C_111が内蔵しているため購入しない |
| 非常停止HW1B-V402R | 2NCの一方で左、もう一方で右の電源を直接切る選定案。ねじ端子、突入適合は未確認 |
| 主電源amon3214 | 計算機を含む全電源の操作用として残す。非常停止とは用途が異なる |
| 電源・分岐ヒューズ | 線材と負荷の保護。特性・線径・コネクタに合わせた最終型番は未確定 |
| 二重リレー・溶着診断 | 旧案の遮断冗長化・故障監視用。初回構成には追加しない |
| 外部ウォッチドッグ・ARMラッチ・専用ARMボタン | 旧案の通信監視・再始動許可用。初回構成には追加しない |
| 低電圧遮断・回生対策 | 不要と証明したわけではない。既存保護と実機電圧を確認してから必要な対策を選ぶ |
| 車載計算機と給電部材 | LinuxミニPCを搭載。Pi 5固定ではなく、機種・価格・実品外形は未選定 |

電源は電池→主ヒューズ→主電源の後で左右モーターと計算機へ分岐する。非常停止時もPC/Picoは給電を維持する。0V帰路、通信ピン割当、分岐は[配線構成](../pico-control/WIRING.ja.md)に示した。現物端子番号・ハーネス型番・線長まで確定した製作配線表は未完。

内蔵電気ブレーキは速度モードの0x64指令DATA[7]=0xFFを使う機能で、通電した制御が必要。非常停止による電源断後の制動・坂道保持は保証しない。対象は平坦な屋内床。独立した安全監視・再始動防止機能を備える構成とは扱わない。[メーカー説明書](https://d2air1d4eqhwg2.cloudfront.net/media/files/a48110eb-432c-4083-a159-9e0f35913b23.pdf)

E3 CADでは旧ARM・旧非常停止・不要な電装予約容積を撤去し、ねじ端子非常停止用ケースとPicoケースを反映した。基板積層高さとコネクタは仮形状のため、現物で仮合わせする。手持ちPicoのヘッダー状態とAmazon HATの価格・回路改訂は未確認。

[撤回した旧回路部品6,519円](withdrawn-parts.ja.md)と[今は購入しない部品](deferred-parts.ja.md)は現行購入BOMから分離した。主電源621円は購入対象へ戻し、ARM835円は外したまま。新しい非常停止2,387円＋表示送料780円を計上したが、未計上品があるため差額を完成車の節約額とはしない。

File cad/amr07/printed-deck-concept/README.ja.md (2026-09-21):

# 格子穴付きPLA上板 P0 — 強度評価前の試作案

> **現行案は[D3：一枚アルミ天板を下段3030へ直接固定](../aluminum-direct-deck/README.ja.md)。** 嵩上げを廃止し、干渉・図面・再見積・BOMを更新した。以下は旧構成の履歴。

> **2026-09-22：角棒の切断・穴あけが必要な支持構成はユーザー判断で不採用。** このページのP0 CAD・画像・費用は比較履歴として残す。切断済み3030・既製ブラケットへ置換したP1を別に作成した。D2荷台の同じ角棒から作る支持ブロック・ストッパーも見直し対象。

**上板の3Dプリント化は候補にできる。今回、50mmピッチ・M4用の格子穴36個を持つ4分割板をCADにした。** 既存A6のアルミ板を同じ厚さのPLAへ置き換える構成は採らず、内側3030にも金属支持棒を追加し、板厚を10mmとした。通常積載10kg、構造検証15kg・安全率2という要求は維持するが、PLA案での達成は未確認。

[組立FCStd](AMR01_PrintedDeck_P0.FCStd) / [組立STEP](AMR01_PrintedDeck_P0.step) / [印刷・比較資料ZIP](printed-deck-P0.zip) / [費用差分CSV](comparison_bom.csv) / [形状検査](validation.json) / [計算](screening.json)

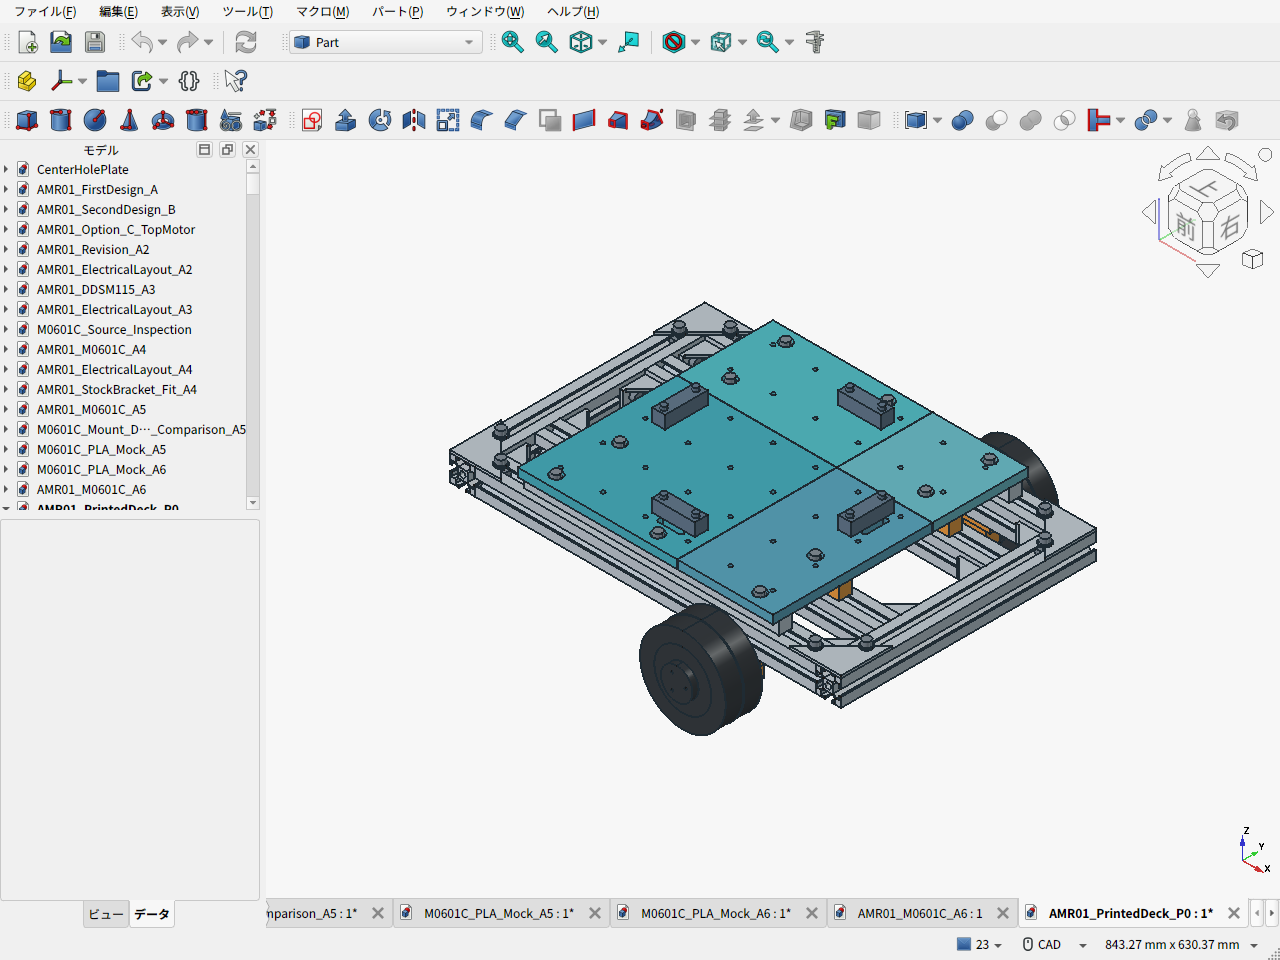
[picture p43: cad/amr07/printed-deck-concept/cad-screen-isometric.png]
PLA案のFreeCAD画面


## 穴と分割

| 項目 | P0 |
|---|---|
| 上板全体 | 300×300、上面z124mm。旧上面118mmから6mm上がる |
| 板厚 | 10mmの中実形状。8mm案との比較から選んだ試作開始値 |
| 格子穴 | 50mmピッチ、6×6＝36か所。原点は板中央、x/y＝−125,−75,−25,25,75,125mm |
| 穴径 | φ4.5通し穴、M4用。底面に対辺7.3×深3.4mmの六角ナット用ポケット |
| 分割位置 | x/y＝37.5mm、隙間0.4mm。格子穴・ベルト長穴・ストッパ穴を継ぎ目で切らない位置 |
| 4枚の外形 | 187.3角、187.3×112.3、112.3×187.3、112.3角。いずれも厚10mm |
| 支持 | 既存外側2本＋追加内側2本の15角金属棒。下の3030へ荷重を伝える |
| 締結 | 元の外側6か所＋内側4か所。金属スリーブ10個で、ボルトの締付力を金属支持棒へ伝える |

手持ちP1Sの公式造形範囲は256×256×256mm。全パネルがこの範囲に収まる。[メーカー仕様](https://store.bblcdn.com/7032c40b1ca64c70bcb3239d46cc72aa.pdf)

格子穴のナットは使う位置だけ入れる。取り付ける部品・座金の厚さに合わせてねじ長さを決め、先端を上板下面より下へ出さない。ナットは組付け前に裏から入れる。支持棒に近い穴のナット交換にはパネルを外す。小径ねじの機器にはプリントした変換プレートを使えるが、個々の機器が50mm格子へ直接取り付く意味ではない。

格子穴に固定した部品の重量・重心は車体と積載の条件へ算入する。アームの曲げモーメントや吊上げ荷重を、この穴配置だけで許容したものではない。荷台に荷物を置く場合、荷物直下にボルト頭や機器を残さない。

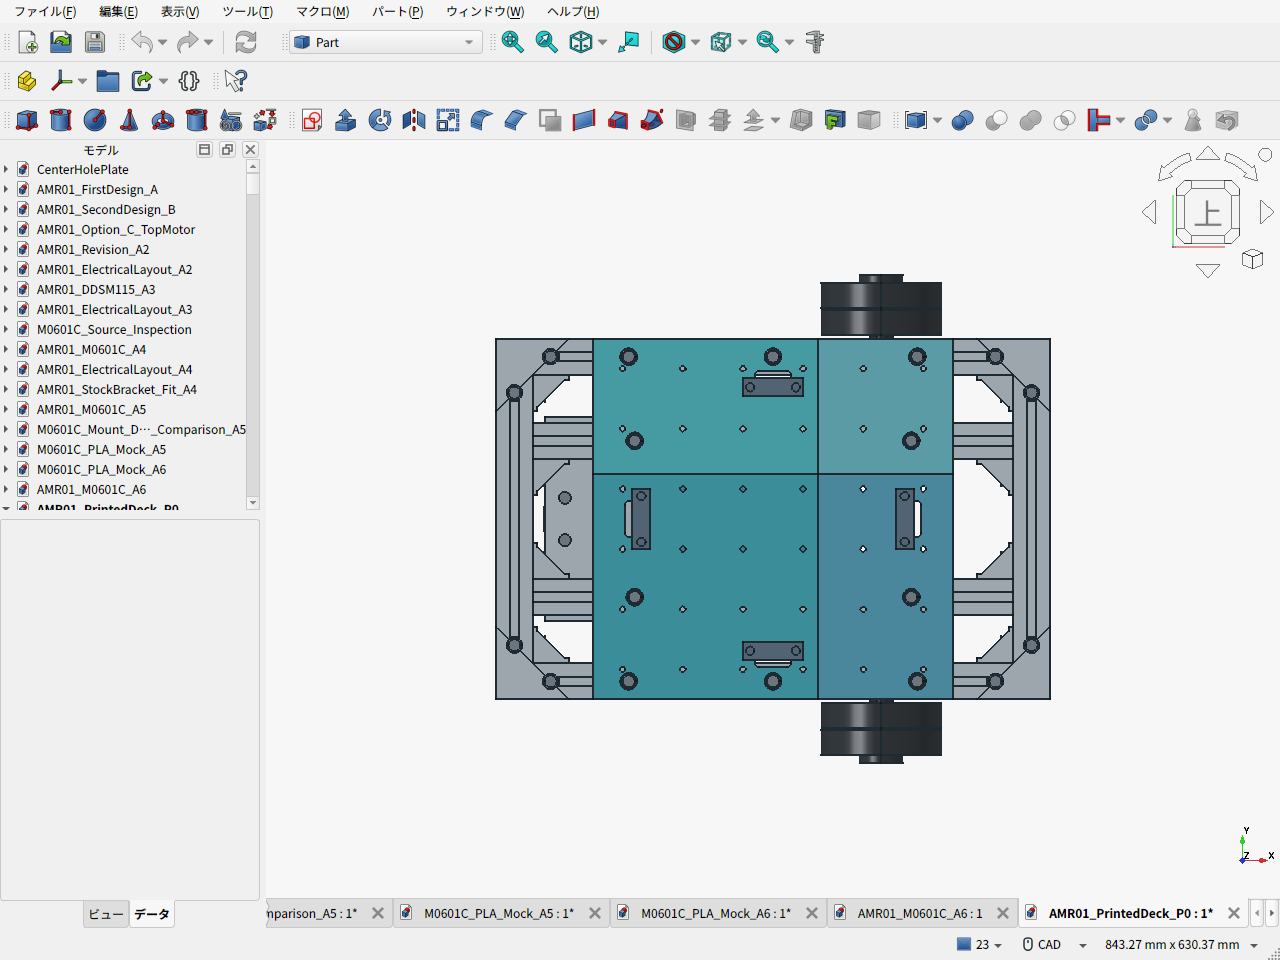
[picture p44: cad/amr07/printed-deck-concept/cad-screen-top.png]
格子と分割の上面


## 支持・ねじ・配線との取り合い

内側支持棒はy＝±65、外側は±135mm。追加の内側取付ねじはx＝±115mmとして200角の平底荷物から外した。旧電装トレイ2枚とその締結材は追加支持棒に干渉するので、P0では外している。前後の新電装予約は維持したが、実部品の取付と配線の確定は残る。

座金下面を従来のz118mmに置くため、厚い上板にφ14の座ぐりを設ける。厚さ1.6mmの座金を2枚入れ、ボルト頭下面はz121.2mmとなる。圧縮スリーブは外径10・内径6.6・長さ4mmの候補で、金属座金→スリーブ→金属支持棒という締付力の伝達経路を作る。スリーブの購入型式、実寸、プリント穴との嵌合、座面の高さ、公差と締付力は未確定。公称形状で接触していることだけで締結成立とは扱わない。

### 中間の支持棒と下側3030の締結

中間材は**15×15×300mmのアルミ角棒4本**。M6×30ボルトを上から入れ、座金2枚、金属スリーブ、角棒のφ6.6通し穴を経由して、下側3030の上向き溝に入れたHNTT6-6ナットへ締める。外側は1本あたり3か所、内側は1本あたり2か所で、合計10か所。角棒へのタップ加工はない。

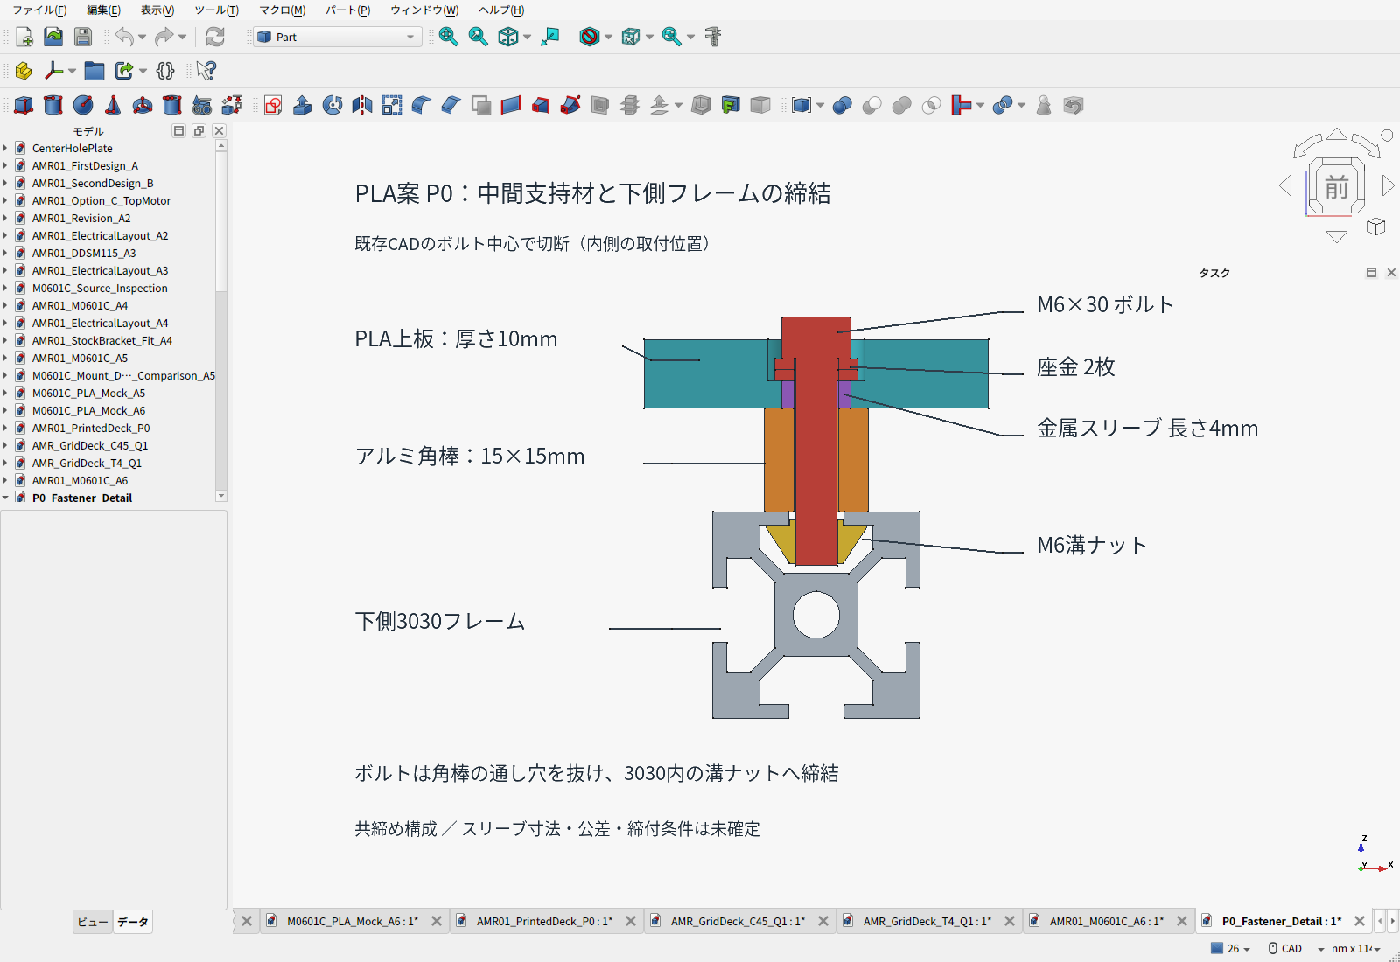
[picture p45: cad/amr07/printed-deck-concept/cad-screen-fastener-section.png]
既存P0 CADから切り出した締結部断面


[断面のFreeCADファイル](P0_Fastener_Detail.FCStd) / [切断位置と元部品の記録](fastener-section.json) / [画像の再生成スクリプト](capture_fastener_detail.py)

これは上板と角棒を同じボルトで保持する**共締め構成**。上板用ボルトを外すと、その角棒の固定も解ける。支持棒を独立固定するねじは現状のP0にはない。断面画像は内側の取付位置x115・y65mmを既存CADから切り出した説明用で、P0の形状や締結方法を変更したものではない。スリーブとPLAの残り厚さは公称でともに4mmのため、実寸差によるPLAの圧縮やがたつきは未検証。

ベルトが内側支持棒を横切る位置には、**PLA側**の下面に26×32×深2mmの逃げを設けた。支持棒を追加で削る形にはしていない。実ベルト・保護材の厚さと、張力下の擦れを確認する。ストッパは元の金属品を使い、固定ねじ8本をM4×30へ変更した。

CADでは227物理形状がvalid、体積干渉0、参照形状との干渉0。36個の各格子穴についてM4ねじ・ナットの公称形状が入ることを確認した。工具の回転、印刷誤差、変形、実機取付を保証する検査ではない。

## 強度・たわみの比較

Bambu PLA Basicの比較用曲げ弾性率は2,750MPa。元のアルミ計算70,000MPaと比べ、同じ形状なら線形計算のたわみは約25倍になる。メーカーの試験片は100%充填と熱処理・乾燥を行った条件で、手持ちPLAや今回のプリントの許容応力には直接使えない。耐熱変形の掲載値54〜57℃も、荷台の連続使用温度の保証ではない。[メーカーTDS](https://store.bblcdn.com/s7/default/b189de92249a4b9ebed28b8ea1f080f0/Bambu_PLA_Basic_Technical_Data_Sheet.pdf)

継ぎ目で曲げを伝達しないものとして、最も張出しが長いパネルを2支点の梁で比較した。中央200角への荷重、板側自重1.6kg枠、ベルト4脚×20Nを含む。ナット穴とベルト逃げについて、全厚の帯を失った扱いにして有効幅を86.0mmまで減らした。外側支持に浮上り反力が出るため、固定ねじで押さえられることが前提である。

| 条件 | 8mm板 | 10mm板 |
|---|---:|---:|
| 通常10kg：短期たわみ、E＝2,750MPa | 1.67mm | 0.86mm |
| 構造15kg：短期たわみ、E＝2,750MPa | 2.09mm | 1.07mm |
| 構造15kg：柔らかい側の感度E＝2,000MPa | 2.88mm | 1.47mm |
| 構造15kg：外力2倍の公称曲げ応力 | 9.50MPa | 6.08MPa |

E＝2,000MPaは感度を見る仮定で、材料の保証下限ではない。上の数値は短期の簡易比較で、穴や長穴の局所応力、接触、締結、層間、クリープ、温度、衝撃を含む安全率2の証明ではない。10mmを初回の試作候補とし、実材料・造形条件による長時間荷重、孔まわりの抜け、支持部の浮上りと締結を確認してから常用の判断をする。

## 費用と重量

| 費目 | 比較用の額 |
|---|---:|
| PLA4枚の固体形状、約1,072g | 約2,143円（既存仮枠2円/g） |
| 追加支持棒用995mm定尺1本 | 1,507円（既存販売記録） |
| 上記2項目の比較額 | 約3,650円 |
| 置換対象のアルミ板1枚 | 4,521円（既存販売記録、穴加工前） |
| スリーブ・ねじ差額・新送料・工具・印刷諸費 | 未確定 |

**板と追加支持材だけなら約871円低いが、完成構成で安くなるとはまだ確定できない。** 格子穴とナットポケットを印刷で作れる利点を含めて比較する。100%形状の材料量であり、スライサー算定、パージ、失敗分、電力、作業時間はまだ計上していない。手持ち材料も消費評価し、0円とはしていない。元のPLAトレイ減少分の費用はこの表で相殺していない。

支持棒は元の1本から残った短材では足りず、追加の995mm材を1本購入する。そこから300mm×2本を切り出して穴を4か所加工する。[既存の販売参照](https://store.shopping.yahoo.co.jp/akibaoo/4977720061511.html)。価格は今回再取得した加工見積ではない。外すトレイの溝ナット8個のうち4個を追加支持部へ転用できる。

車体重量は元のA6推計を基に**約9.047kg**。10kgまで約0.953kgだが、スライス・実測前であり、今後の機器追加を無条件に許容する余りではない。[計算内訳](validation.json)

## 印刷データの位置付け

4枚のSTLは、上面を下にして造形台へ置く向きで出力した。最初に小片でφ4.5穴・六角ナット・圧縮スリーブの嵌合を確認する。形状の比較は中実相当を前提としており、任意の低充填率に変えて同じ強度計算を使わない。実スライス、反り、印刷品質、長時間荷重の検証は未実施。

既存A6のCAD・見積済みモーター金具・購入BOMは比較基準として保持した。P0は格子穴と樹脂化を検討する別の試作候補で、現時点の購入BOMへ二重計上しない。

```sh
python3 cad/amr07/printed-deck-concept/screening.py
# build_concept.py は独立したFreeCADのheadlessプロセスで実行
```

P0を再生成する際の元車体・荷台パラメータはgit改訂`7f6bf0501322def11120138fecc62a40ea970170`へ固定した。現在のD2を旧P0の支持構成へ混ぜない。履歴を含むgitチェックアウトが必要。

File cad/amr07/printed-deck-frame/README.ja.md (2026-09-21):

# P1：切断済み3030と既製金具で支える分割PLA荷台

> **P1は比較履歴です。** ユーザー指示により[直付け一枚アルミ天板D3](../aluminum-direct-deck/README.ja.md)へ変更しました。上段フレームを廃止し、干渉修正・再見積・BOM更新まで反映済み。

> **継ぎ目レビュー：支持・連結の修正が必要。** 各板にM6固定2本はあるが、隣接板は0.4mmの隙間で突き合わされ、継ぎ目同士の連結はない。最長132.3mmの片持ち部分があり、板端の相対段差・変形は未検証。[確認結果と修正条件](SEAM_REVIEW.ja.md)。以下のCAD・STLは修正前のP1。

2026-09-22。「三角フレーム」は**溝付きフレーム**というユーザーの補足を反映した。旧P0の中実角棒4本を、300mmの3030フレーム2本とミスミHBLFSN6ブラケット8個へ置き換えた。**荷台支持用の金属材を自宅で切断・穴あけする工程はない。** モーター支持の見積済み専用金具、下段の既存取付板は別の製作範囲。

これは公称寸法で組付けを確認した試作設計。通常積載10kg、構造検証15kg・安全率2は設計目標として維持するが、**P1のPLA荷台の強度・クリープ・実荷重試験は未完了**。旧アルミD2の解析結果をP1の耐荷重として使わない。

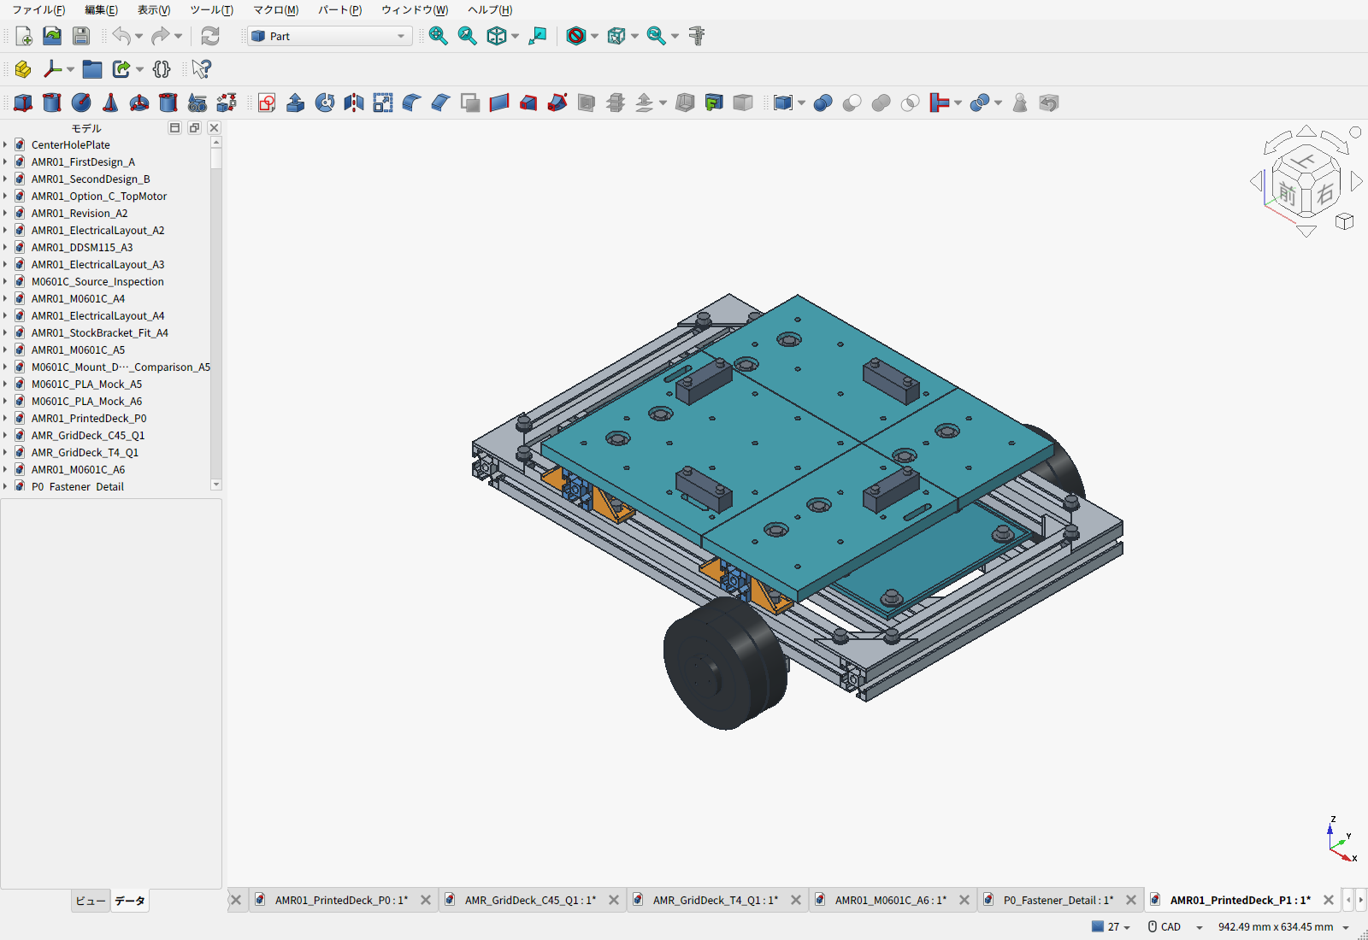
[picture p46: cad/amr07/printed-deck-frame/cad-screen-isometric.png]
P1のFreeCAD実画面


**格子穴付き上板はこのP1にも組付け済み。** 300×300mmの4分割PLA板に、50mmピッチ・φ4.5の拡張用穴を6×6＝36か所残している。M4ボルトと裏側のナット用ポケットで機器を固定できる。下の締結説明図だけは、支持部分を見せるため上板を非表示にしている。

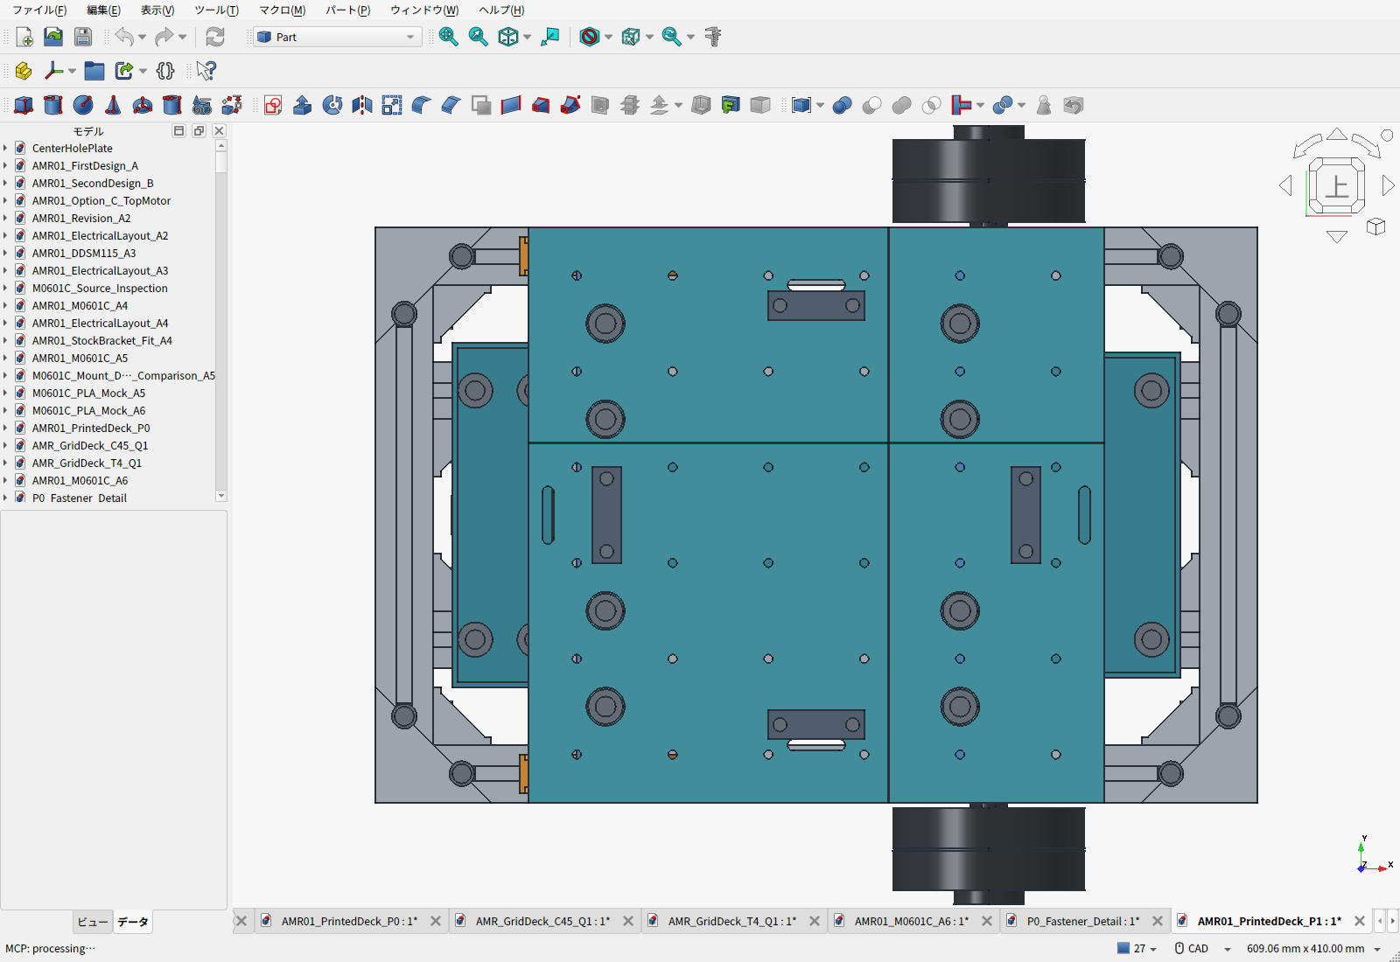
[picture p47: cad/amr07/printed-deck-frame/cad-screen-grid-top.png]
格子板を載せたP1の真上からのCAD画面


## 上下フレームの締結

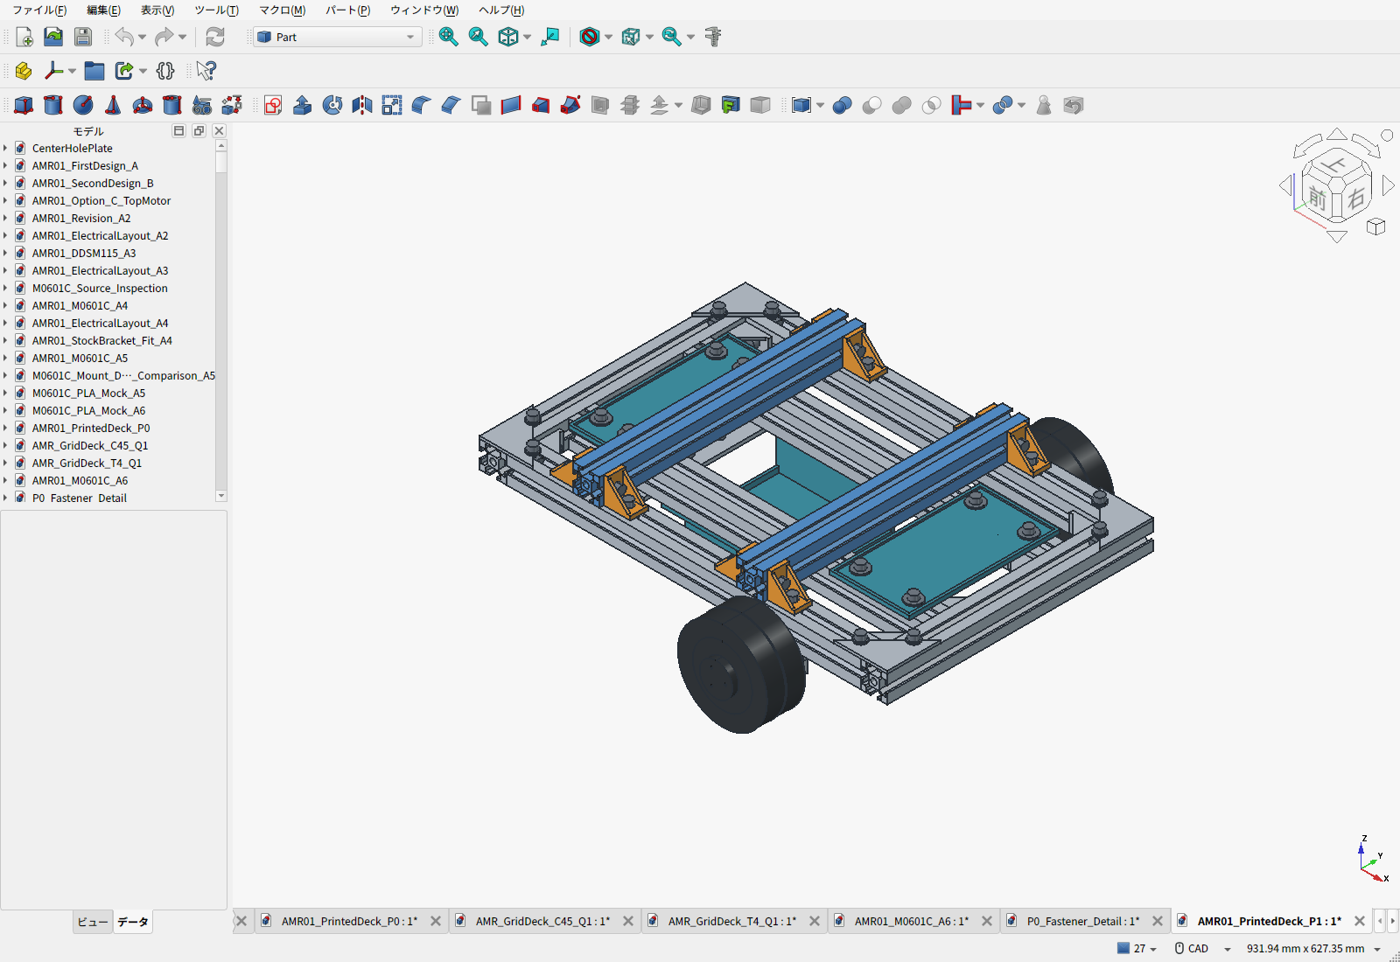
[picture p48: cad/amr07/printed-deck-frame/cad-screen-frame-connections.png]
締結確認用：格子板を一時的に非表示にした上下フレーム


青色が追加した溝付き3030、橙色が購入する反転ブラケット。色はCAD上の識別用で、製品の塗装指定ではない。

- 上段はNFSL6-3030-300を2本、Y方向に配置。中心X=-110/+75mm、下面Z99/上面Z129mm。
- それぞれの上段材は、下段の4本の400mm材に直接載る。荷重は接触面から下段へ伝わる。
- 外側の下段材との交差部4か所を、両側からHBLFSN6で固定する。計8個、M6×12とHNTT6-6各16個を追加。
- ブラケットの縦面は上段の側面溝、足は下段の上面溝に固定する。フレームに追加穴を開けない。
- PLA荷台のM6固定8本と、フレーム接合のM6固定16本を分けた。板を取り外しても、上下フレームの接合は残る。

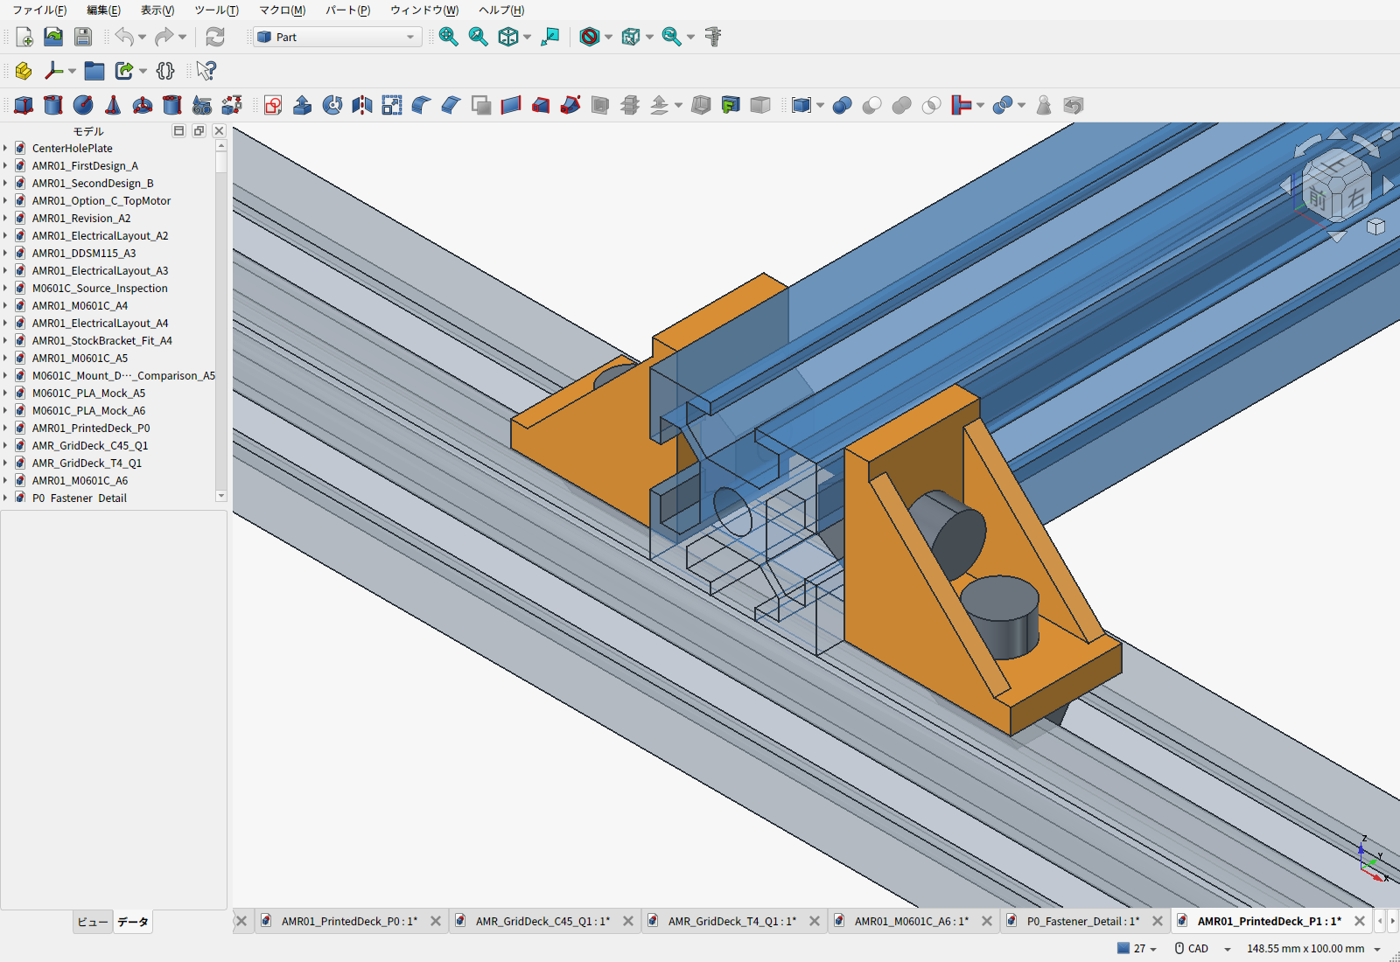
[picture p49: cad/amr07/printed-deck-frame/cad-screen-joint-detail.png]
交差部の拡大・フレームを半透明表示


メーカーはHBLFSN6のL字・クロス接続への対応、M6×12/HNTT6-6、質量15gを公開している。[メーカー仕様](https://jp.misumi-ec.com/vona2/detail/110300442340/) / [接続例と寸法図](https://jp.c.misumi-ec.com/book/MSM1_F24/pdf/0304.pdf)。CADは30×30×20mmと穴位置から再構成した簡略形状で、鋳造丸み・溝位置決め突起は省略した。壁厚を4.5mmの包絡で扱い、実物が4mmの座面の場合もM6×12先端と溝底に公称1mmの余裕がある。製品CADそのものではないため、突起の向き、実ねじ長さ、ねじ込み、公差は現物で照合する。カタログ1176Nを今回の車体全体の保証荷重に換算しない。

## 寸法・印刷・整備

| 項目 | P1 |
|---|---|
| 下段フレーム | 外形460×300mm、床上69～99mm。変更なし |
| 上段 | 切断済み3030×300mmを2本、床上99～129mm |
| 荷台 | 300×300×12mm、4分割、上面**床上141mm** |
| 旧P0との差 | 上面124→141mm、**17mm上昇**。30mmの支持高さと12mm板厚による |
| 格子穴 | 50mmピッチ、φ4.5の36穴。底面にM4ナット用対辺7.3×深さ3.4の印刷ポケット |
| 印刷サイズ | 最大187.3×187.3mm。全10個の新規STLがP1Sの256mm角に収まる |
| ストッパ | 15×15×50mmの交換可能なPLA部品4個。穴も印刷。荷物の主固定は既存の交差ベルト2本 |
| 車体重量 | **推計9.419kg**、10kgまで約0.581kg。電池・電装2.10kg枠、ベルト等0.280kgを各1回含む |

板の固定には既製のアルミカラー（外径12/内径6.2/長さ5mm）を印刷部内へ入れ、その上に外径18×厚さ1.6mmの座金2枚を置く。M6×16ボタンボルトの頭は上面より公称0.5mm低く、ねじ先端はフレーム溝底から公称1.2mm離す。12mm厚は、この沈め込み寸法と曲げ剛性を考えた試作値であり、強度計算による認定厚さではない。カラーと印刷した座面の段差・座金厚さを試験片で測り、板が遊ぶ/PLAを強く潰す組合せを避ける。カラーは高さ追加用ではなく、板内の締結座として使用する。

2本の横桟で4枚を個別に支えるため、各パネルは2本のM6で固定する。最も長い片持ち部分は、左フレーム内側端X=-95から分割端X=37.3までの132.3mm。旧P0の支持条件とは違う。分割端、薄くなるナットポケット・固定座、ベルト溝、ボルトによる浮上り拘束、PLAの時間/温度依存を含む検証が必要。中実形状の板4枚は約1.275kg。低いインフィル率へ変えて同じ耐荷重を仮定しない。

左横桟をX=-110にしたのは、電池の120×80×65mm予約を削らず、側方5mmの公称隙間と上向き取り出し経路を確保するため。電装トレイは前90×170mm・後55×180mmに再印刷し、内側固定穴も移した。トレイの固定は各4本を維持した。電装はまだ予約外形であり、実際の基板・コネクタの取付確認は残る。

荷物とベルトを外し、上板のM6×16を8本抜いて4枚を取り外すと、電池を真上へ取り出せる。上段3030と8個のブラケットを外す必要はない。ベルトX方向の穴は左右X=±140に移動し、横桟を越える部分だけPLA裏面に48×26×深さ2mmの溝を印刷した。金属フレームには切欠きを作らない。

荷物CG上限は床上220mm、車体CG上限目標は110mmのまま。板が高くなったため、同じ容器を置けば荷物CGも上がる。CADの例示荷物は200×200×150mmで、均一密度ならCG216mm。実際の荷物・機器配置についてこの値を保証しない。

## 費用と購入単位

300mm材は、既存BOMの**4本入り1組1,467円**を下段2本＋上段2本で使い切る。上段のためにもう1組買う必要はない。すでに所有しているという意味ではなく、初回購入するパック内の割当変更。[Amazonの300mm材](https://www.amazon.co.jp/dp/B0DKDZ8G9G)

2026-09-22に商品名と商品価格を確認。送料・配送先別Prime条件・最終会計は別。

| 部品 | P1全車の使用数 | 購入数量・表示価格 |
|---|---:|---:|
| [HBLFSN6](https://www.amazon.co.jp/dp/B0DKF1FCD6) | 下段8＋上段8＝16個 | 10個917円×2＝1,834円。ねじ・ナット別売 |
| [HNTT6-6](https://www.amazon.co.jp/dp/B0DK9C99YH) | 基礎44＋追加24＝68個 | 50個2,556円×2＝5,112円 |
| [アルミカラー12×6.2×5](https://www.amazon.co.jp/dp/B0GWMC8ZY9) | 8個 | 10個580円 |
| [M6×16ボタンボルト](https://www.amazon.co.jp/dp/B0C2CDH79R) | 8本 | 10本410円 |
| [大径座金18×6.4×1.6](https://www.amazon.co.jp/dp/B0G2X4FSQX) | 荷台固定用16枚 | 50枚845円 |
| ブラケット用M6×12 | 全車32本 | 販売パック・強度区分・価格未確定 |
| ストッパ用M4×30/M4ナット | 各8個 | 販売パック・価格未確定。既存D2のナットがあれば再使用 |
| 車体のPLA全11部品 | 中実換算約1.535kg | 手持ち材料2円/gの参考消費評価、切上げ3,072円。実スライス未実施 |

P1ではCNCアルミ荷台板・その送料・角棒材料・角棒送料を削除した。購入型番が違う商品へ遷移した検索結果は見積根拠にしなかった。価格が未確定のねじを0円と扱って完成価格を作らない。途中小計は**54,074円＋82.25 USD＋未確定分**。USD分は従来のモーター金具加工とその表示送料。[P1全車BOM CSV](BOM.csv) / [途中小計・未計上項目・価格記録](cost_summary.json)。従来BOMの予算枠も引き継ぐため、完成車の確定見積ではない。

## CAD検査とファイル

273物理部品・37,128ペアで公称体積干渉なし。36穴のM4ナット/ねじ包絡、M6用工具の直線進入、荷台と電池の上向き180mm連続取り出し、変更部品とキャスター旋回包絡を検査した。ブラケットの足を締める工具は上板を付ける前の状態で確認した。下段と駆動系の変更していない部分は、固定したD2リビジョン3417383の形状・検査に依存する。タイヤ変形や未モデル化した突起・実公差・配線全長まで検証したという意味ではない。

- [組立FCStd](AMR01_PrintedDeck_P1.FCStd) / [組立STEP](AMR01_PrintedDeck_P1.step)
- [全検査結果・質量内訳](validation.json) / [設計値](parameters.json)
- [印刷ファイルとサイズ](print_manifest.json)：同じフォルダの10個のSTL。荷台4枚は上面を下にした配置。座ぐりのブリッジ/支持材・穴精度はスライサーと試験片で確認する。P1S用の確定印刷プロファイルではない。
- [印刷用STL一括ZIP](P1-print-files.zip) / [CAD・画像・STLのハッシュ](release_manifest.json)
- [再生成スクリプト](build_p1.py) / [BOM生成](build_bom.py) / [CAD画面撮影](capture_screens.py)

旧P0とアルミD2のファイルは履歴として保存する。新しい支持構成の試作にはこのP1を参照する。

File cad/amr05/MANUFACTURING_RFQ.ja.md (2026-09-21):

# M0601C_111 専用モータ金具：見積依頼仕様案

作成日：2026-09-21。図番 **AMR-05 / MOUNT-Q01、Rev. A**。

**この資料は見積用。現物照合と最終図面の承認前は製作を保留する。** 2026-09-21にSTEP・PDFをJLCCNCの自動見積へ投入した。[取得結果](MACHINING_QUOTE.ja.md)は2個74.50 USD＋国単位の日本向け送料7.23 USD。正式な図面審査依頼・発注・支払いは未実施で、以下の検査・税等を含む着荷総額の確認は残る。

## 依頼内容

Direct Drive Tech製 M0601C_111 を3030アルミフレームへ固定する、一体のアルミ金具を2個製作する場合の見積を求める。左右で同じ部品を使用する。溶接組立ではなく、一体CNC加工を第一候補とする。

モータの受け部は[既製DDT-M0601C-BRACKETの公開CAD](https://www.switch-science.com/products/9204)にある解析曲線を参照している。**モータ側形状参照、車体側は新規設計**であり、既製品の複製や完全なSTEP変換品ではない。詳しい由来は[BRACKET_SOURCE_REVIEW.ja.md](BRACKET_SOURCE_REVIEW.ja.md)を参照。

| 項目 | 見積条件 |
|---|---|
| 数量 | 同形2個。左右別形状にはしない |
| 材料 | A6061-T6を第一希望。変更提案は見積に明記し、承認前に置換しない |
| 加工 | 材料手配を含む一体CNC加工。切削面のままを見積基準とし、装飾用の表面処理は要求しない |
| 外形 | 90 × 30 × 34 mm |
| フレーム取付フランジ | 90 × 30 × 厚さ5 mm |
| モータ支持web | 幅60 × 厚さ17 × 高さ34 mm |
| 体積・質量参考 | CAD体積38,440.7525 mm³、密度2.70 g/cm³の仮定で約104 g/個 |
| 納入時状態 | 切粉除去・バリ取り。ケーブル接触部を傷つけない端部処理を含む提案を求める |
| 見積金額 | 2個合計 **Q円＝材料＋加工＋検査＋梱包＋消費税＋送料**。含まない費用は分けて表示 |
| 回答に含める事項 | 納期、見積有効期限、適用する公差・表面粗さの前提、工具上必要な内隅R、追加費用となる条件 |

部品単価だけでなく、**同形2個を受け取るまでの総額Q**で比較する。 BOMではこのQを金具本体Q01と製作送料S08に分けて記録する。送料込み一式見積をQ01へ入れる場合は、S08を「Q01に含む」と明記して0円へ変更する。未確認の送料を0円にせず、見積総額と送料を二重計上しない。見積依頼時に納入先が未記入なら、送料を確定するための郵便番号を添える。

## 添付する形状資料

- [M0601C_custom_mount_quote.step](M0601C_custom_mount_quote.step)：切削する公称形状。
- [M0601C_custom_mount_quote.pdf](M0601C_custom_mount_quote.pdf)：A3見積用寸法図。
- [M0601C_custom_mount_quote.svg](M0601C_custom_mount_quote.svg)：同じ寸法図のベクターデータ。
- [custom_mount_dimensions.json](custom_mount_dimensions.json)：主要寸法と設計の前提。

図面の投影は同梱STEPから生成している。見積対象のSTEPを取り違えないよう、図面右下にSHA-256の先頭16桁を記載した。図面上の実測長ではなく寸法数値を使用する。モデルと記載寸法に差があれば加工せず、相違を照会する。

## 部品座標と加工箇所

ここではSTEPの外形最小隅を **O=(0,0,0)** とする。元CADが車体座標で保存されている場合は、(45,120,35)を差し引くと下記の部品座標になる。原点出ししたSTEPの場合、この差引きは不要。

Xは幅方向、Yは厚さ方向、Zは高さ方向。モータは+Y側から取り付ける。上の3030接触面はZ=34、フランジ下面はZ=29、モータ軸中心は **X=45、Z=15.35**。軸はY方向。

| 加工・基準 | 部品座標での寸法 |
|---|---|
| フランジ外形 | X=0…90、Y=0…30、Z=29…34 |
| 支持web | X=15…75、Y=10…27、Z=0…34 |
| モータ受け入口 | Y=27 |
| 受け底 | Y=18。入口から深さ9 mm |
| web背面 | Y=10。受け底との間に8 mmの肉厚を残す |
| M6用通し穴 | 2 × φ6.6。軸はZ、中心(X,Y)=(7.5,15)、(82.5,15)、ピッチ75 |
| モータ用通し穴 | 3 × φ2.8。軸はY、PCD15.2、下表の位置 |
| 受け主輪郭 | 元の解析輪郭を外側へ0.15 mmオフセット。主円弧R9.70、回り止め3平面の軸距離8.25 |
| 配線開口・背側 | 幅7 mm、中心X=45。下側へ開放。中央上端はR3.5 |
| 配線開口・モータ側 | 幅9.5 mm、Y=18…27。中央上端はR4.75 |
| 配線開口・下端 | Z=0…6では背側も幅9.5 mm。中央ねじ頭の座面を残すため、全高さを幅9.5にはしない |

モータ用φ2.8穴の中心は以下の3点。穴位置の基準は軸中心X=45、Z=15.35である。

| 穴 | X mm | Z mm |
|---|---:|---:|
| 上 | 45.000000 | 22.950000 |
| 左下 | 38.418207 | 11.550000 |
| 右下 | 51.581793 | 11.550000 |

すべてブラケット側の**通し穴**であり、ブラケットにM2.5やM6のタップを立てる指定ではない。受け部の細かい円弧接続と配線切欠きはSTEPの公称輪郭を参照する。

## 公差案と、製作前に確定する事項

回り止め3平面の軸距離について、見積用の公差案を **8.25 ±0.05 mm** とする。モータ側の同じ距離を8 ±0.15 mmとした場合、ポケット最小8.20とモータ最大8.15との差は片側0.05 mmになる。ただし、この計算が扱うのは**平面部分のみ**である。

主円弧、隅の円弧、深さ、穴位置、実際に納入されるモータの版、バリや表面処理まで含む**全輪郭の公差適合は未確定**。円弧を含む輪郭全体へ、平面寸法の±0.05を自動的に適用しない。穴位置公差、一般公差、接触面の平面度・直角度、必要表面粗さも今回のモデルだけでは確定していない。加工先は見積時に適用予定値と追加費用を提案し、最終図面の承認後に製作する。

特に、次を製作承認前に確認する。

1. 実機の固定ボスと金具の全輪郭が入り、回り止め面が機能すること。必要な逃げ量を現物に合わせて確定する。
2. 工具径・内隅R・底隅Rを加えても、モータ座面が浮かず、軸位置と取付ねじの座面が成立すること。CADの鋭角を加工都合で無断変更しない。
3. 受け底、web背面、3個の通し穴、3030接触面・2個のフレーム穴の位置関係が、合意した公差内にあること。
4. 工場出荷ハーネスとコネクタが開放部へ入り、取付・取外し時にも傷つかないこと。背側7 mmの開口とねじ頭の座面を両立すること。
5. 端部処理を加えた後も、フランジの5 mm厚さとM6ねじ頭座面、モータ用ねじ頭の座面が残ること。

原CADには解析輪郭があるため、その輪郭のはめあいまで画像や寸法図の線幅から推定しない。現状の公称CADでの部品間干渉ゼロは、加工公差、締結強度、耐久性、実組立の保証を意味しない。

## 組立情報（見積金具には締結品を含めない）

- モータ固定：1個当たりM2.5 × 12を3本。背面肉厚8 mmに対する公称ねじ込みは4 mm、モータ側の最大有効深さ5 mm以内。実際のねじ長さ公差・座面・ボス端面位置を現物で再確認する。
- フレーム固定：1個当たりM6 × 12を2本、厚さ5 mmのフランジへ頭を直接着座させる。現設計は座金なし。別途用意する3030用ナットの寸法・ねじ込みも組立時に照合する。
- 見積の金具は左右同形2個。ねじ・フレームナット・モータ・電装品はQに含めない。

## 費用比較の基準

[既製DDT-M0601C-BRACKET](https://www.switch-science.com/products/9204)は、確認時点で1個6,050円（税込）、2個12,100円（税込）だった。**既製品案には別途3030取付板の材料・加工と追加締結品が必要**なので、12,100円だけを既製案の完成費用とはしない。送料条件も揃えて比較する。

専用案の比較対象はQに、その案固有の締結品等を加えた金額。既製品2個＋自作3030取付板一式との完成条件を揃えて選ぶ。専用一体加工が安くなる保証はなく、Qが不利なら、配置・加工方法・既製品を使う案へ戻って比較する。現時点で発注は行わない。

## 図面の再生成

`python3 cad/amr05/make_mount_drawing.py` でSVG/PDFを再生成する。別プロセスのheadless FreeCADでSTEP投影を作り、Rsvg/CairoでPDF化する。原点が車体座標か部品座標かは外形の最小隅から吸収する。主要寸法や体積が変更された場合は、古い注記を残さずスクリプトを停止するので、図面注記も見直す。

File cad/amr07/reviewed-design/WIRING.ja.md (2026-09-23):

# E4 配線構成と制御の役割

**車載LinuxミニPC → USB → 手持ちPico → 完成済み2CH RS485基板 → 左右モーター。** PCとPicoの両方を同じRS485バスのマスターにしない。USB–RS485変換器、裸の変換IC、専用監視基板は購入しない。

## 電源

```mermaid
flowchart LR
 B[BL1860B＋アダプター] --> F0[電源直近 F0]
 F0 --> S0[主電源 S0<br/>amon3214]
 S0 --> FL[左モーター用 FL]
 S0 --> FR[右モーター用 FR]
 S0 --> FC[計算機用 FC]
 FL --> SA[非常停止S1・NC接点1]
 FR --> SB[非常停止S1・NC接点2]
 SA --> ML[左 M0601C_111]
 SB --> MR[右 M0601C_111]
 FC --> PS[選んだPCに適合する給電部材]
 PS --> PC[LinuxミニPC]
 PC -->|USB給電・通信| P[Pico＋RS485基板]
```

S1は**HW1B-V402R 1個の2NC接点を左右へ1つずつ使う**。同じボタンで両方を開く。2接点を並列につないで電流定格を増やす構成ではない。S0は全電源の通常操作用で、Linuxを終了してから切る。S1を押してもPC/Picoは給電を維持する。

電池マイナスから、左右モーターの電源GNDとPC給電部材の入力GNDへ、それぞれ電力用の帰路を用意する。信号GNDの細線やUSBシールドをモーター電流の帰路にしない。PC給電部材が絶縁型の場合の0V接続も、その製品決定時に図へ反映する。

| 接続 | 接続先・端子 | 線材の設計目安／残る確認 |
|---|---|---|
| 電池＋ → F0 → S0 → 分岐 | アダプター出力＋、S0の2接点 | 幹線1.25mm²を初期目安。付属線・250型端子・突入適合を確認 |
| S0後 → FL → S1のNC1 → 左モーター＋ | NC1の両ねじ端子、モーター電源コネクタVCC | 延長幹線0.75mm²目安。モーター付属細線／コネクタへの変換は完成ハーネスで確定 |
| S0後 → FR → S1のNC2 → 右モーター＋ | NC2の両ねじ端子、モーター電源コネクタVCC | 左と同様 |
| 電池− → 左右モーターGND | 電源コネクタGNDへ独立した支線 | ＋線に対応した線径。付属ケーブルの許容電流が優先 |
| S0後 → FC → PC給電部材 → PC | 選定機種の入力＋／−、出力端子 | PC機種未選定。電圧・コネクタ・極性を決めてから接続 |
| PC → Pico | USBデータケーブル | 通信と給電を兼用。別電源をPicoへ重複接続しない |

NC1/NC2は**この設計で左右を識別する名前**で、メーカー刻印の端子番号を創作したものではない。公開資料の端子図・適合電線に基づく製作配線表への展開、端末型式・線長の確定は未完。M3.5ねじ端子は、メーカー指定の接続方法または端末加工済み線で使い、ユーザーのはんだ付けを前提にしない。

電源予算はモーター入力の参考3A×2台、PC側30W、最低電圧16.5V、変換効率仮定85%で約8.14A。S0のDC24V10A表示を超えない設計枠だが、**突入の適合証明ではない**。F0 10A、FL/FR/FC各3Aは選定開始値であり、ヒューズ特性・線材・コネクタ・起動挙動に合わせて確定する。30A付属ヒューズだけで細線を保護できるとは扱わない。

HW接点はメーカー表でDC24V・DC-12 10A／DC-13 5A。1接点1モーターに分けるのは、この範囲に余裕を取りやすくするため。ドライバーの入力コンデンサ突入や遮断時過渡は別に確認する。[IDEC資料](https://www.tdcjapan.com/wp-content/uploads/2017/06/P5204A-HW-with-RemovableContactBlock.pdf)

## 通信

| 系統 | Pico | RS485基板 | モーター |
|---|---|---|---|
| 左 | UART0：GP0 TX／GP1 RX | CH0 A／B／GND | 左A(DATA+)／B(DATA−)／信号GND、ID1 |
| 右 | UART1：GP4 TX／GP5 RX | CH1 A／B／GND | 右A(DATA+)／B(DATA−)／信号GND、ID2 |

115200bps・8N1・10バイトのメーカー独自プロトコルを使う。Modbusではない。基板はPicoソケットから給電し、**モーター用18Vを基板の信号端子へ入れない**。基板両側の同一CH端子は別チャンネルとして数えない。終端抵抗・A/Bの表示・送受信切替動作は購入基板とモーターで確認し、抵抗を無条件に追加しない。[基板の公式配線](https://www.waveshare.com/wiki/Pico-2CH-RS485)／[モーター説明書](https://d2air1d4eqhwg2.cloudfront.net/media/files/a48110eb-432c-4083-a159-9e0f35913b23.pdf)

## Picoのソフト設計

- 左右それぞれ100Hzを初期設定として指令送信・応答取得。左右の回転方向符号は車輪を浮かせて確認する。
- 起動時は速度ゼロ。PCの明示的な走行開始操作を受けてから動かす。
- PC指令が200ms途絶える、またはモーター応答に異常が出た場合、ゼロ指令を送り、走行指令を禁止する。復帰後は新しい開始操作を要求する。
- 通常停止は速度指令をゼロへ下げる。内蔵電気ブレーキは速度モードの0x64指令DATA[7]=0xFFで作動させ、効き方を実機確認する。
- 非常停止による直接電源断は、上記のソフト処理を待たない。電源断後の制動・坂道保持は保証しない。

これは**ソフトの設計であり、ファームウェア実装・動作試験済みではない**。専用ARMボタンは設けない。非常停止検出用の追加接点もないため、短時間の電源遮断など全事象をPicoが検出する保証はなく、独立した再始動防止回路とは異なる。Pico自身の故障時はソフト停止を保証せず、物理的な電源遮断が別経路として残る。

## 「不要」と決めていないもの

電池・アダプターの保護、減速・遮断時の電源電圧、モーター入力突入は確認項目として残す。低電圧遮断器や回生抵抗を未確認のまま購入必須にはせず、既存構成で不足が判明した場合に対策を選ぶ。裸ICを並べた未完成回路をユーザーに製作させる方針には戻さない。

## E4レビュー反映：復帰と配線製作

停止・起動・通信異常後には、USB受信待ちやモーター送信待ちに残る古い指令を破棄する。左右どちらかの応答異常/ドライバー故障でも両輪への走行指令を禁止する。復帰は両輪へゼロ指令で通信を再確立し、新しい明示的なRUN操作を受けてから行う。非常停止を解除する前にPC側のRUNを解除する。短い断電を必ず検出する機構はなく、独立した再始動防止回路の実装完了を意味しない。

非常停止の表示は「MOTOR STOP／モーター電源停止」、黒い主電源は「MAIN POWER／PC終了後OFF」。実品のON/OFF方向と一致する表示を付ける。表示の製作方法・位置はREADMEの操作面図を参照し、CADで電気的なON向きを保証しない。

| 配線 | 製作方法 | 現時点 |
|---|---|---|
| PC–Pico USB | 既製データケーブル | 両端型式・長さ未確定 |
| モーター電源/RS485 | モーター付属線を優先、不足は端末加工済みハーネスを購入または加工依頼 | コネクタ型式・線径・端末表未完 |
| 主電源250型端子 | 絶縁付きメス端子の加工済みリード | 250型適合はメーカー指定済み。接続端子/完成リードの購入型式未選定 |
| HWねじ端子 | メーカー指定端末処理済み線を調達 | 適合端末と刻印端子番号の照合待ち |
| 分岐/ヒューズ | DC定格の既製ホルダーと適合配線 | 最細線・突入に合わせる最終型式未確定 |

箱の内側に配線結束橋を追加した。端子に引張荷重をかけず、側面開口には縁保護を付ける。蓋を50mm上へ動かすための配線余長は初期設計目安100mmを確保し、ループの曲げ・蓋閉鎖時の挟み込みを実配線で確認する。配線加工設備をユーザーが所有する前提にはしない。

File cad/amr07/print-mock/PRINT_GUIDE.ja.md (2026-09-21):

# A6-R1 M0601C_111 金具：PLA 仮合わせモック

**形状と手組みの確認専用。車体支持・走行・荷重試験に使わない。金属加工への製作承認、荷物 15 kg の構造成立、安全率 2 の確認とは別である。**

A6-R1 の元 STEP を等倍で使用する。実モーターの購入ロット、ねじ、座金、3030 の受入測定と実際の金属金具の検証は未実施。小型確認片で入るかどうかを確かめてから、全体を印刷する。

<!-- source-mock:start -->
改訂：**A6-R1**。元STEP：`../M0601C_mount_A6_R1.step`。

本体外形：**90×30×34 mm**。フランジ厚：**5 mm**。M6穴ピッチ：**75 mm**。寸法は元STEPの形状から取得。確認片は24×29×17 mm。
<!-- source-mock:end -->

| ファイル | 印刷時の寸法 | 用途・最初の数量 |
|---|---|---|
| `M0601C_seat_A6_fit_coupon.stl` | 24×29×17 mm | 固定端の受け、3 穴、座金座ぐり、配線逃げの確認片。まず 1 個 |
| `M0601C_mount_A6_R1_PLA_mock.stl` | 90×30×34 mm | 金具全体。まず 1 個。確認後に必要なら同一品を計 2 個 |
| `M0601C_PLA_Mock_A6.FCStd` | 本体＋確認片の並列表示 | FreeCAD で確認する文書。STL は各部品単独 |
| `validation_results.json` | — | 元 STEP と仕様 JSON のハッシュ、解析面、切出し、STL 再読込検証 |

配布 ZIP は `M0601C_A6_PLA_mock_files.zip`。P1S の公称造形範囲 **256×256×256 mm** に両方とも単体で収まる。[Bambu Lab P1S 公式仕様](https://us.store.bambulab.com/collections/3d-printer/products/p1s)。STL は単位を保持しないため、Bambu Studio で **mm・倍率 100%** とし、表の寸法を照合する。左右用も鏡像化せず、組立時に回転配置する。

## 確認片に含む形状

元のローカル座標 `[33,10,0]` から **24×17×29 mm** を切り出した。受け開口が印刷時の +Z、背面がベッド面となる姿勢へ回転済みである。受け深さ 9 mm、背面厚 8 mm、R1.62 の小円弧 6 箇所、R9.67 の大円弧、次の変更を含む。3030 取付フランジと M6 穴は含まない。

- M2.5 ねじ用の **φ3.2 通し穴を 3 箇所**。PCD15.2。受け中心より穴群中心が 0.17 mm 上にある設計を保持する。
- 背面に **φ6.2×深さ 0.5 mm の座金座ぐりを 3 箇所**。残る直線穴の長さは 7.5 mm。
- 背面の配線通路 **幅 6.5 mm**。前側と下端の逃げは幅 9.5 mm。

公差と着座方向は [金具インターフェースレビュー](../MOUNT_INTERFACE_REVIEW.ja.md) と [元仕様](../M0601C_mount_A6_R1.json)、[加工図](../M0601C_mount_A6_R1.pdf) を参照する。これらはリポジトリ側の資料で、印刷 ZIP には含めない。

## 仮合わせの順序

1. 確認片を 1 個印刷し、反り、初層の膨らみ、穴と座ぐりの塞がり、受けのサポート痕を確認する。背面がベッド側なので、深さ 0.5 mm の座ぐりは下面にある。削った箇所と補正値を記録する。
2. モーターを別の台で支え、固定端を押し込まず手で当てる。設計上の車体 +Z 側へ軽く着座させ、端面との接触と 3 穴の位置を確認する。**印刷時の +Z は受けの開口方向で、車体 +Z とは異なる。** モーターが未入手なら形状・工具アクセスの予備確認までとする。
3. 金具 1 個につき **M2.5×12 を 3 本、小径平座金 2.7×5×0.5 を 3 枚**使用して、ごく軽く仮合わせする。現候補は WILCO FC-2512 と FW-2505-05EB。座金が座ぐり内でねじ軸へ追従し、首下丸みに乗らず、全周が平らに座ることを確認する。浮きを増締めで潰さない。PLA に金属用の締付トルクを適用しない。[ねじ販売元](https://wilco.jp/products/F/FC.html)、[座金販売元](https://wilco.jp/products/F/FW-EB.html)
4. 寸法だけの公称ねじ込みは `12−(8−0.5+0.5)=4 mm`。公差を含む幾何値は 3.50〜4.50 mm だが、完全ねじ山の長さ、許容予圧、硬い穴底までの距離を保証しない。実モーターの入口・深さを確認し、底付き、ねじの斜め入り、抵抗があれば止める。ねじでモーターを受けへ引き込まない。
5. 実際のケーブルと保護材を通し、幅 6.5 の区間、曲げ、擦れ、引張り止めを確認する。予約された φ6 経路だけでは実束線やコネクターの通過を保証しない。座金と配線開口の狭い縁も観察する。
6. 全体を 1 個印刷する。90×30 mm の3030接触面がベッドになる姿勢としてある。車体とモーターを別に支え、3030 へ M6×12 と対応溝ナットで軽く仮固定し、75 mm の穴ピッチ、工具、配線、タイヤ交換時の空間を確認する。フレームねじも現物の座り・底付きを確認する。形状確認後、必要なら同じ STL をもう 1 個印刷する。

モックが組み付いても、受けの接触圧、ねじ母材・引抜き、予圧、座金曲げ、溝縁、疲労、モーターの許容輪荷重は確認できない。

## スライサーと記録

実際の PLA、ノズル、プレートのプロファイルを優先する。0.4 mm ノズルでの開始案は積層 0.16 mm、外周 4、インフィル 20%。いずれも未スライス・未実印刷の提案値で、強度条件ではない。確認片は受けを上向きにし、サポートなしのプレビューを先に確認する。全体の横向き小穴と受けはオーバーハングがあるので、必要なサポートをプレビューで判断する。

全体の拡大縮小は穴ピッチも変えるため 100% を維持する。XY・穴・初層の補正を使う場合は値を記録する。元 CAD へ印刷用の逃げや補正を足していない。

**FDM の寸法誤差と金属加工公差は別である。** PLA の収縮、積層、反り、初層、除去痕が影響する。印刷物の合否だけで受けの輪郭公差域 0.10 mm、穴位置度 φ0.10、背面厚 ±0.05、φ3.2 穴の指定公差などを認定しない。金属寸法の変更は実モーターの測定と加工条件で判断する。

モーター型式・版、材料、ノズル、積層・補正、穴加工や削りの有無、座金の座り、受け接触、配線・工具アクセスを残す。生成時に単一の閉じたメッシュ、非多様体・自己交差、外形寸法、体積、元 STEP との一致を確認するが、印刷成功とは別の検証である。**スライス・実印刷は未実施。印刷時間、使用フィラメント量、印刷費は未算出**。Bambu Studio の実スライス結果から確認する。

## 再生成と GUI 確認

FreeCAD Python 環境で `QT_QPA_PLATFORM=offscreen freecadcmd /absolute/path/cad/amr07/build_print_mock.py` を実行すると、GUI なしで STL、FCStd、検証 JSON、ZIP を生成する。元 STEP と仕様 JSON のハッシュが合わない場合は停止する。元の A4/A5 ファイルは書き換えない。

headless 生成した FCStd は画面表示状態の保存を別途行う。FreeCAD GUI で現在のファイルを開き `build_print_mock.finalize_gui_preview()` を呼ぶと、両形状を表示、保存、撮影し、検証 JSON と ZIP を同期する。既に表示・保存・撮影した場合は `refresh_bundle_after_gui()` で同期だけを行える。STL は再生成しない。保存で BRep のバイト列が変わった場合も、以前の FCStd、元 STEP、体積・位相・境界・両方向の形状差分を別の headless プロセスで確認し、一致した場合だけハッシュを更新する。

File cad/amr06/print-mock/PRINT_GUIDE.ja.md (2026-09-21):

# A5 M0601C_111金具：PLA仮合わせモック

**D5は比較用CAD・仮合わせモックで、金属加工への採用は保留です。コスト低減案としては採用していません。可搬15 kgと安全率2も未認定です。**

A5の `selection.json` で選択した候補STEPから等倍で作成する。受けの逃げR2、受け深さ9 mm、背面厚8 mmを引き継ぐ。幅・フランジ厚・取付穴ピッチは候補により異なるため、下の生成記録を確認する。**形状・手組みの仮合わせ専用で、荷重試験・車体支持・走行に使う金具ではない。** 可搬重量や安全率2の確認には使えない。

<!-- selected-mock:start -->
選択候補：**D5**。元STEP：`../candidates/M0601C_mount_D5_Compact_R2.step`。

本体外形：**75×30×34 mm**。フランジ厚：**6 mm**。M6穴ピッチ：**60 mm**。寸法は選択STEPの形状から取得。確認片は24×29×17 mm。
<!-- selected-mock:end -->

| ファイル | 印刷時の寸法 | 用途・最初の数量 |
|---|---|---|
| `M0601C_seat_A5_fit_coupon.stl` | 24×29×17 mm | 固定端の受け・3穴・配線切欠きの確認片。まず1個 |
| `M0601C_mount_A5_selected_PLA_mock.stl` | 上の生成記録に示す本体外形 | 金具全体。まず1個、形状確認後に左右用として同じものを計2個 |
| `M0601C_PLA_Mock_A5.FCStd` | 本体＋確認片の並列表示 | FreeCADで形状を確認するための文書。STLは各部品単独 |
| `validation_results.json` | — | 元STEPのハッシュ、寸法、STL再読込検証、確認片の切出し検証 |

配布ZIPは `M0601C_A5_PLA_mock_files.zip`。P1Sの公称造形範囲は256×256×256 mmで、両方とも1個で収まる。[P1S公式仕様](https://cdn1.bambulab.com/documentation/quick-start-59b0cefdc0fc4/P1S/English%20version-Quick%20Start%20Guide%20for%20P1S.pdf)。STLには単位情報がないため、Bambu Studioへ**mm・倍率100%**で読み込み、表の寸法を確認する。

## 仮合わせの順序

1. 確認片を1個印刷する。受けが上を向き、背面がベッドに接するSTLとして出力する。本体幅をWとしたローカル座標 `[W/2−12,10,0]` から24×17×29 mmを切り出して印刷姿勢へ回転してある。受け深さ9 mm・背面厚8 mm・M2.5通し穴・配線の逃げを含み、3030固定穴と外へ張り出すフランジを含まない。A4の中心を選択候補の中心へ移動して比較し、受けの6か所の逃げR2拡大を反映する。根元R2の追加材料が範囲外であること、背肉と3穴が保たれることを検証結果へ記録する。
2. 実モーターがあれば、押し込まず手で当て、固定端、3穴、ケーブルの逃げを確認する。まだなければ形状と工具アクセスの予備確認まで。印刷物だけでは購入ロットの適合を確定できない。
3. 全体を1個印刷する。W×30 mmの3030接触面をベッドに置く姿勢としてある。3030へ軽く仮固定し、上の生成記録にあるM6穴ピッチ、モーター位置、配線、工具、タイヤ交換時の空間を確認する。
4. 全体の形状確認後、必要なら同じSTLをもう1個印刷する。左右は回転配置で使い、鏡像化しない。

仮組み中は車体とモーターを別の台で支え、PLAへ主荷重を掛けない。金属用の締付トルクをPLAへ適用しない。モックの外形が成立しても、金属金具の強度・疲労・締結・モーター許容荷重を確認したことにはならない。

## スライサーで確認する条件

実際のノズル、プレート、PLAプロファイルを優先する。0.4 mmノズルなら積層0.16 mm・外周4・インフィル20%を仮合わせの開始案とし、小さい確認片で調整する。これらは未スライス・未実印刷の提案値である。

確認片は受けが上、凹部底がベッドから8 mm、入口が17 mmとなる。サポートなしのプレビューを先に確認する。本体は側面の受けと小穴にオーバーハングがあるため、必要なサポートをプレビューで判断し、除去痕が受けや穴を塞いでいないか確かめる。

全体の拡大縮小は穴ピッチも変えるため100%を維持する。XY補正・穴補正・初層補正を使用した場合は値を記録する。元CADへ印刷用の逃げや補正は追加していない。

**FDMの公差と金属加工公差は別物である。** 収縮、初層の膨らみ、積層、サポート痕の影響があるので、PLAが入る／入らないだけで金属の受け寸法8.25±0.05 mmや輪郭公差を合否判定しない。金属設計を変える根拠には実モーターの測定と加工条件の確認を使う。

## 残す記録と未実施項目

モーターの型式・版、PLA、ノズル、積層・補正値、受けと穴の合い方、配線と工具の接触を記録する。穴をさらう・サポート痕を削る作業をした場合は箇所も残す。

生成時にSTLの閉鎖性、単一接続、非多様体・自己交差の有無、寸法、体積、STEPとの一致を確認する。これは印刷適性やはめあいの実機保証ではない。**スライス・実印刷は未実施。印刷時間、フィラメント使用量、印刷費も未算出**であり、Bambu Studioの実際のスライス結果から確認する。

再生成はFreeCADのPython環境で `QT_QPA_PLATFORM=offscreen freecadcmd /absolute/path/cad/amr06/build_print_mock.py` を実行する。GUIなしでSTL・FCStd・検証結果・ZIPを出力できる。GUIなしで作成したFCStdは、画面確認と表示状態の保存が別途必要になる。

GUIでは `build_print_mock.finalize_gui_preview()` を呼ぶと、本体と確認片を表示して保存・撮影し、FCStdと画像のハッシュ、検証結果、ZIPを更新する。旧候補の文書を開いたままの場合は、それを閉じて現在のFCStdを開く。既にGUIで表示・保存・撮影まで済ませた場合は `refresh_bundle_after_gui()` で更新だけを行える。どちらもSTLを作り直さない。後者は元STEP・選択・STL・CAD形状が不変であること、保存済みの表示状態と画像の新しさを照合する。

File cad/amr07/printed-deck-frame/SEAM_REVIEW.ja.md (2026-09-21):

# P1天板の継ぎ目レビュー

2026-09-22。ユーザーの「継ぎ目は固定できているか」という指摘を受け、保存済みCADの4枚の板、8本の固定ねじ、隣接面の距離を確認した。[実形状からの確認記録](seam_review.json)。このレビューでは形状を修正していない。

**各板をフレームへ留める固定点はあるが、継ぎ目の支持・連結設計は未解決。現状を完成した荷台として扱えない。**

| 確認項目 | CADの状態 | 評価 |
|---|---|---|
| 板からフレームへの固定 | 各板M6×2本。2本とも同じ上段3030上の一直線に配置 | 板端の荷重・浮上りに対する固定部の剛性検証が必要 |
| 隣接板のつなぎ | 隣接4組とも最短距離0.4mmの突き合わせ | 相じゃくり・ほぞ・裏面連結板・継ぎ目用ボルトはない |
| X=37.5の継ぎ目 | 直下に上段支持材がない | 左側の板端は支持材端から132.3mm、右側は22.3mm張り出す。荷重時の相対段差を確認できていない |
| Y=37.5の継ぎ目 | 上段3030の2本と交差する部分で支持 | 継ぎ目全長を連続支持する構造ではない |
| 既存の検査 | 公称形状干渉、穴位置、ねじ・工具包絡と整備経路を確認 | 継ぎ目の変形・締結部の剛性・長期クリープ・15kg/SF2を検証した結果ではない |

分割板は、それぞれに適切な支持があれば板同士を直接つながない構成も成立し得る。P1については、支持位置から離れた継ぎ目の変形と、一本の支持材に留めた板の荷重伝達を評価できていないため、その条件が成立したとはいえない。

修正では、隣り合う板端から骨格へ荷重を伝える経路を設ける。候補は継ぎ目と支持材の配置を合わせる構成、またはボルトで留める裏面連結材を設けてその曲げ・締結も評価する構成。単に接合用の突起を印刷するだけで耐荷重を認めない。

検討条件は、格子穴36か所へのアクセス、天板を外した電池整備、荷台高さ、車体10kg以下、金属支持材の自家切断・穴加工なし、購入単位での費用。修正形状の支持・接合部を含む変形と強度を確認するまで、P1の荷重使用は未承認のままとする。

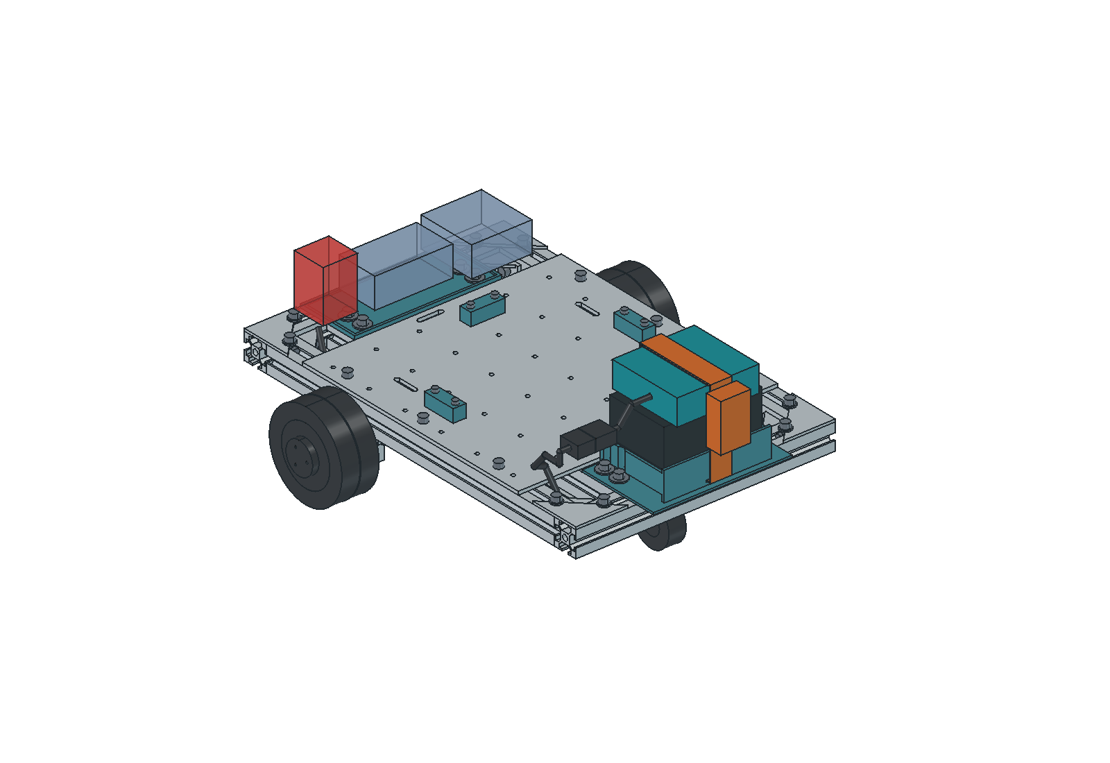
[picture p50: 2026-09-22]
cad/amr07/makita-power/viewport-assembled.png

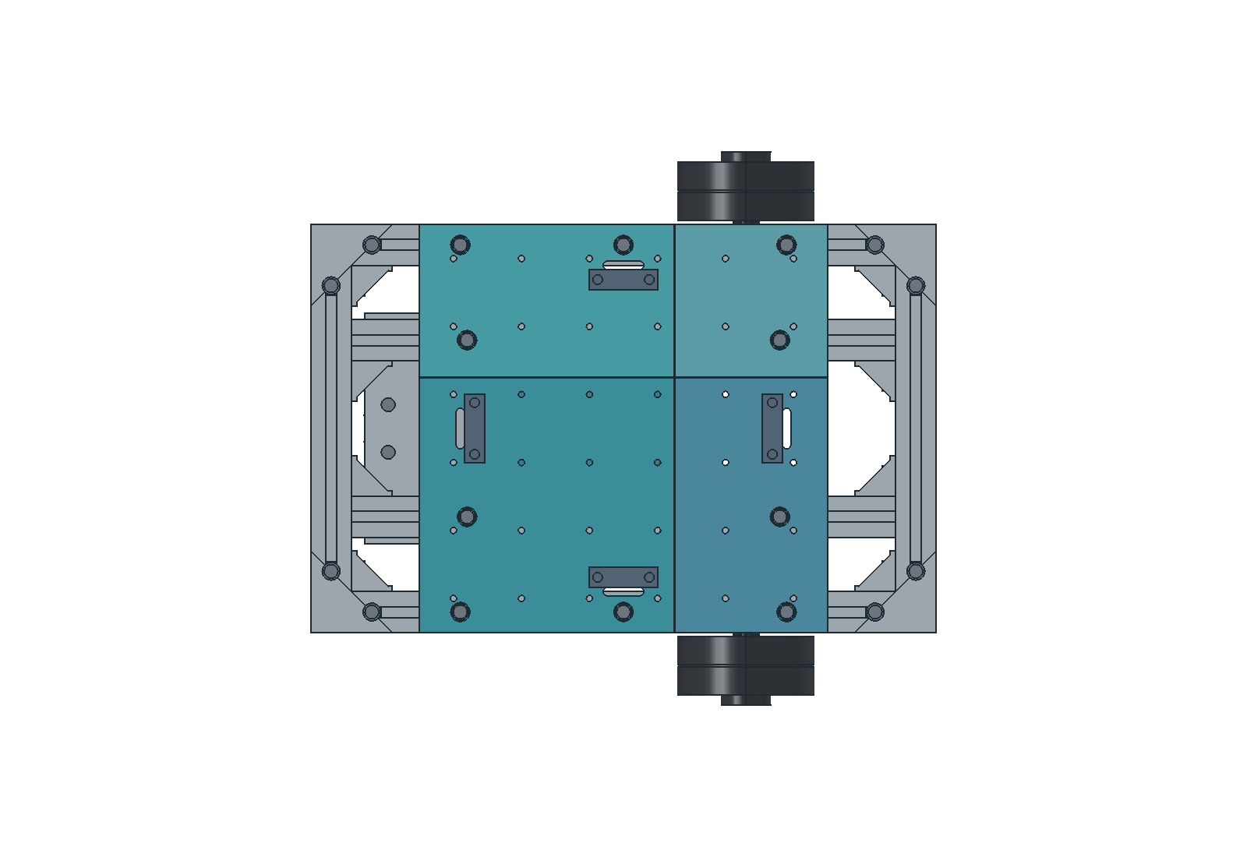
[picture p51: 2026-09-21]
cad/amr07/printed-deck-concept/viewport-top.png

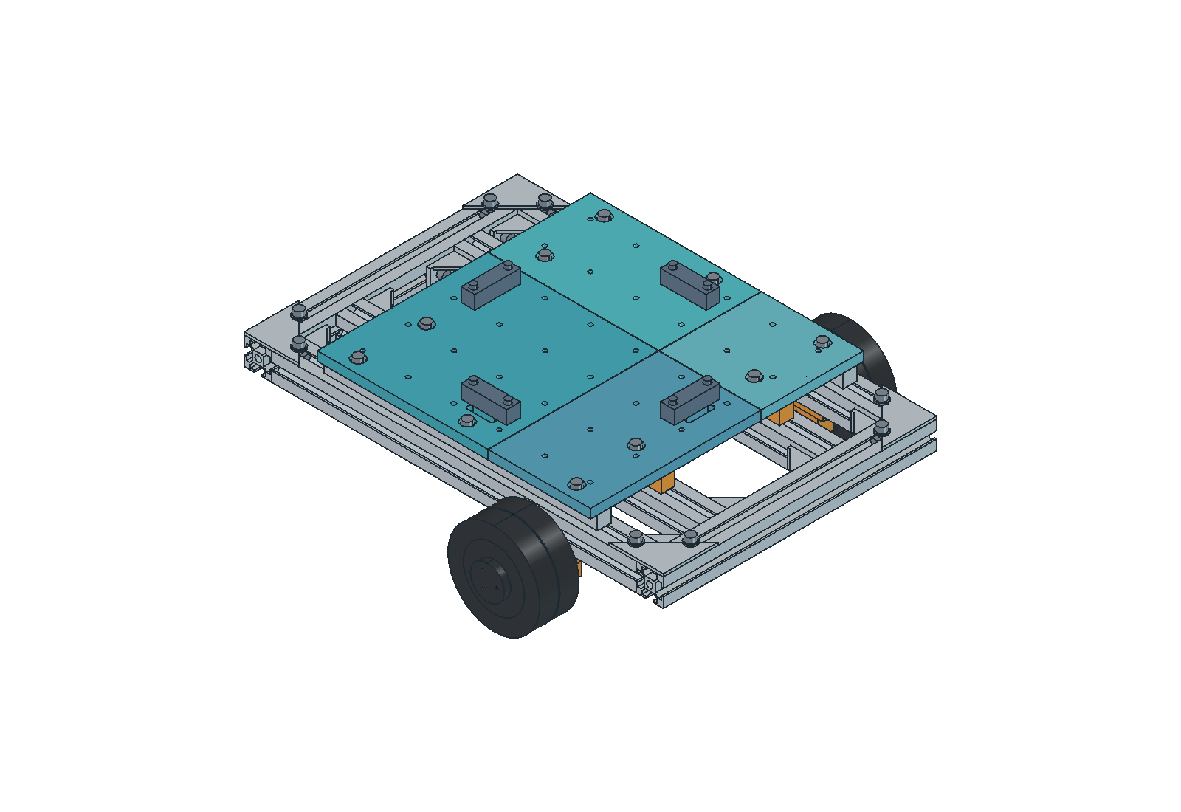
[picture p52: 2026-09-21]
cad/amr07/printed-deck-concept/viewport-isometric.png

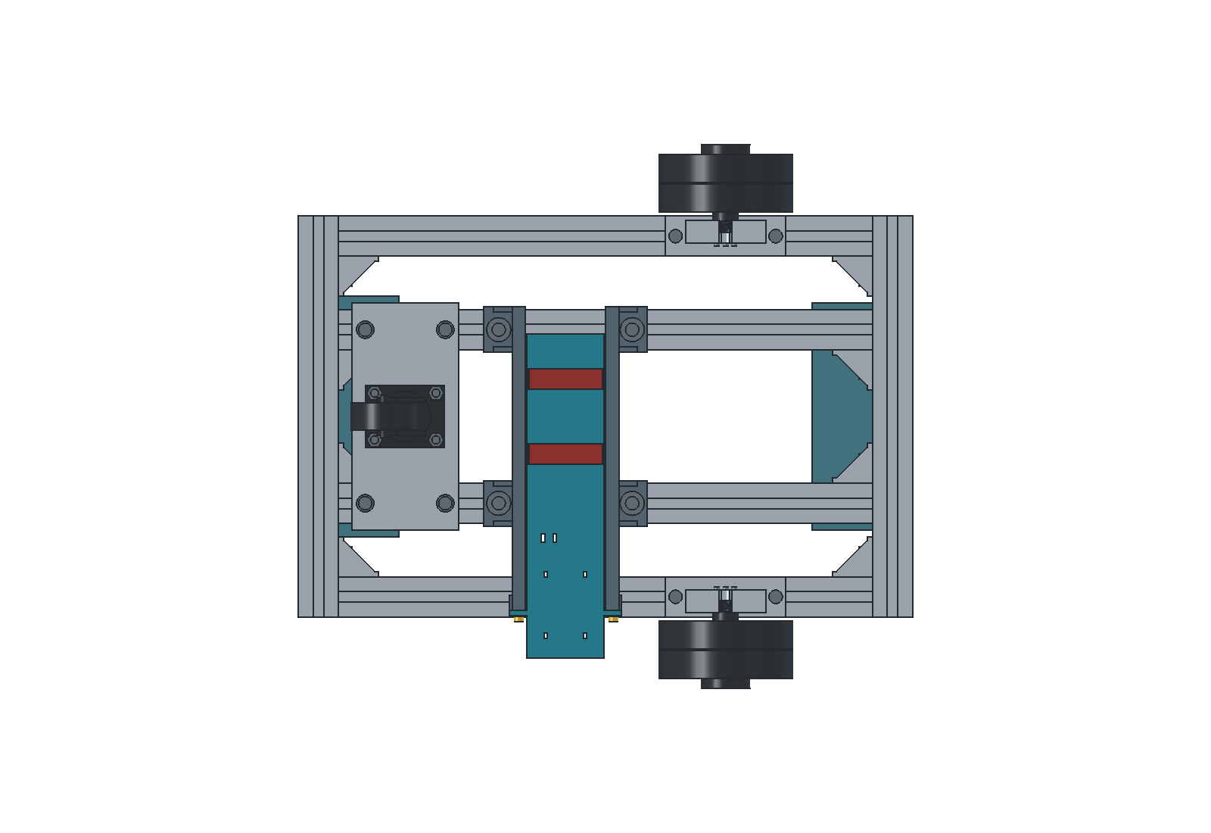
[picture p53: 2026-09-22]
cad/amr07/battery-drawer/viewport-guide-mounting.png

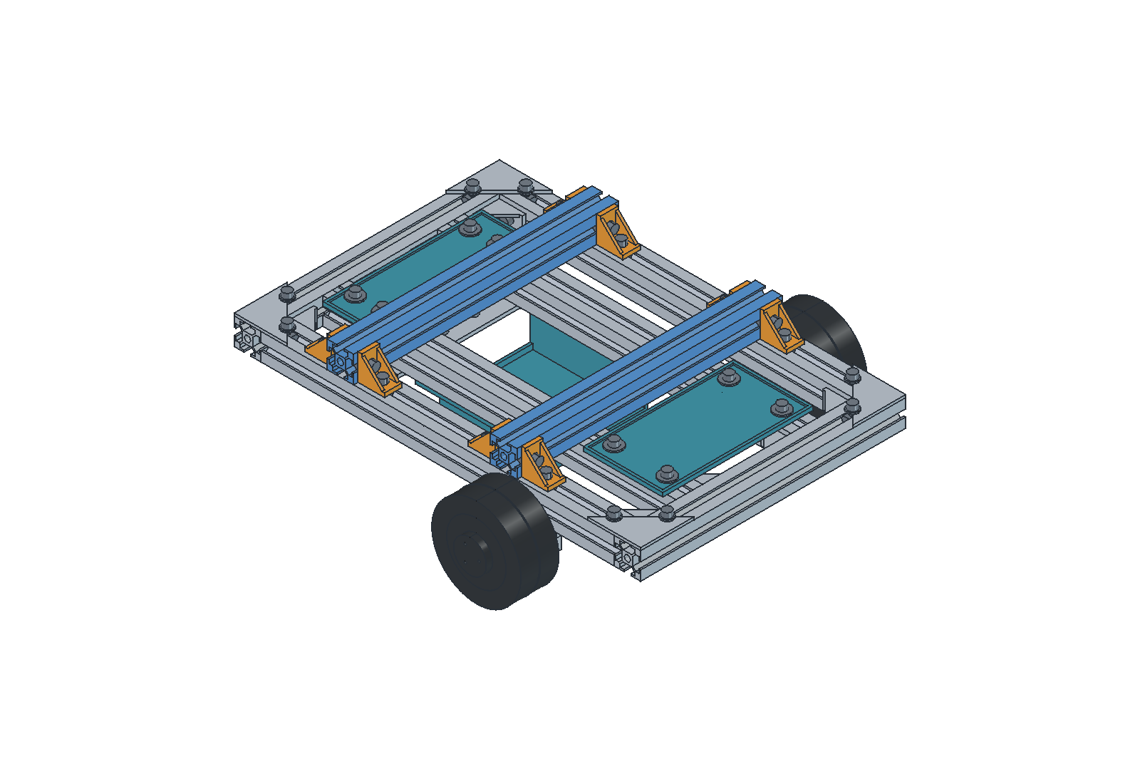
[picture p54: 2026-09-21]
cad/amr07/printed-deck-frame/viewport-frame-connections.png

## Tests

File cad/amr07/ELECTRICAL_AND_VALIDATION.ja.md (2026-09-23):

# AMR 電源・停止の旧要求・回路案（履歴）

**現行はE3：LinuxミニPC → USB → Pico → 2CH RS485基板です。** 後方の2NC非常停止で左右モーター電源を直接遮断する案へ変更し、主電源は残しています。[最新設計](pico-control/README.ja.md)／[配線構成](pico-control/WIRING.ja.md)。以下は旧案の履歴で、現行の必須機能や部品表ではありません。

<details>
<summary>旧案の記録を開く</summary>

2026-09-23更新：現行は[D6.9固定天板・後方操作部](fixed-deck/README.ja.md)。非常停止XA1E-BV302R、手動ARM3212、主電源3214は後方へ配置。Pico本体は手持ち流用で型番・ピン有無確認待ち。[製造・既製モジュール比較](control-layout/ELECTRONICS_OPTIONS.ja.md)／[現行BOM](fixed-deck/BOM.ja.md)。固定天板へ変更後も計算・試験条件は車体11.5kg／総21.5kgの範囲を維持する。[D6.9の再計算](fixed-deck/PAYLOAD_REVIEW.ja.md)を参照。

2026-09-22 D6更新：配置を1階電装・2階荷台へ変更。電池は8mm持ち上げて後方へ220mm抜く。電池は**マキタ純正BL1860B 18V6Ah**、充電器は**純正DC18RF**、接続は**Netkey diy-adapter03**を選定した。どちらも未所有という条件で、新規電池・充電器・アダプターの表示送料込み小計23,380円を計上する。[電源選定価格](makita-power/power_selection.json)・[現行CAD配置](fixed-deck/README.ja.md)。車体側の保護回路・実装検証は下記の未完工程として残る。

2026-09-21。M0601C_111 を2台使う家庭用試作の**回路構成案と受入試験仕様**。ユーザー方針により追加機械ブレーキは採用せず、初号機は平坦な屋内床専用とする。通常の減速・停止はモーター制御で行い、非常停止時の駆動電源遮断も維持する。回路基板・監視ファームウェアは未製作で、走行許可はまだ出さない。汎用リレー、独立マイコン、外部監視ICを使う構成であり、産業用安全回路の認証や全単一故障への対応を主張するものではない。

## 運転条件と確認できた仕様

[要求](fixed-deck/requirements.json)に合わせ、平地で荷物10kg＋今回の計算範囲である車体11.5kg＝総21.5kg（車体10kgは目安）。旧条件の5°・荷物8kg／総18kgは参考計算に移し、現在の運用・必須試験には含めない。荷物15kg／総26.5kgは静的構造の条件で、走行定格ではない。初期速度0.15m/s、旋回0.3rad/s、常用加減速度0.2m/s²。初期の左右回転数は18.520〜38.377rpm、後期の0.3m/s＋0.6rad/sでは37.040〜76.755rpmになる。

メーカー現行ページは18V、115rpm、0.96N·m、1.25Aを同じ定格点として示す。拘束2N·m／2.7A以下は連続能力に使わない。巻線温度上限80°C、周囲−20〜45°C。トルク定数0.75N·m/Aも定格速度での値なので、低速の電流から連続トルクを保証しない。[現行仕様](https://shop.directdrive.com/pages/m0601c-111-specs)

販売元が公開するメーカー手順書では、速度モードの駆動指令`0x64`のブレーキ欄`0xFF`が電気ブレーキ、`0x74`で固定子温度を取得する。通信は115200bps、8N1、10バイトのポーリング、上限500Hz。過電流・拘束等には自動復帰動作がある。**通信断から停止する保証時間、ブレーキ時の回生量・吸収能力、無通電保持トルクは確認できない。** 内部保護だけで再始動防止を構成しない。旧手順書の入力上限24Vと現行ページの28Vには差があるため、本案はモータ端で24V未満を守る。[メーカー手順書 pp.7,9–13](https://d2air1d4eqhwg2.cloudfront.net/media/files/a48110eb-432c-4083-a159-9e0f35913b23.pdf)

下記の時間・温度・停止距離は**今回決める試作機の受入値**であり、メーカー保証値ではない。

## 電力の接続案

```text
BL1860B（18V6Ah・最大21.0V、保護適合確認前は未接続）
  └ 電池直近F0 ─ 後方着脱コネクタ ─ 主スイッチ3214 ─ 独立した全負荷遮断
       ├ Fctl ─ 5V/1A専用DC/DC ─ Pico／監視IC／リレーコイル
       ├ Fpc  ─ 主計算機用DC/DC（主計算機決定後に選定）
       └ Fdrv ─ 逆流防止D0 ─ K1のNO ─ K2のNO ─ MOTOR_BUS
                                                    ├ FL ─ 左モータ
                                                    ├ FR ─ 右モータ
                                                    ├ Cbus／放電用抵抗
                                                    └ 自立過電圧クランプ ─ 制動抵抗 ─ 0V
```

K1/K2はG5LE-1 DC5の直列NO接点。片方の接点が溶着した場合にも、もう片方を開ける構成とする。電気ブレーキとは独立して駆動電力を切るが、切った後の車体停止・保持を保証するものではない。リレー定格は**DC30V・抵抗負荷8A**を採る。モータ入力コンデンサの突入電流は別条件なので、8Aの表示だけで投入可能と判定しない。[オムロン資料](https://akizukidenshi.com/goodsaffix/g5le.pdf)

ヒューズの出発点はF0=10A、Fdrv=7.5A、FL/FR=各3A、Fctl=1A。全て24V以上のDC遮断適合品とする。値は確定BOMではなく、実ケーブル・端子の許容電流と突入波形、電池の短絡保護に合わせて時間電流特性を選ぶ。Fpcは未選定計算機に合わせる。主幹・モータ延長線は当面0.75mm²銅線、元の細い付属線は短く保持し、正規圧着・引張り止めを使う。ヒューズは電源側に置き、3030を負荷電流の帰路にしない。

D0候補はSBM1060LSS。電池への逆流を阻止し、回生を車体側抵抗へ逃がす。順方向降下と発熱は損失なので、性能試験の電圧は**電池端ではなくモータ端**で測る。D0、リレー、ケーブルの降下を引かずに18V定格と比較しない。充電は停止・電池分離後、DC18RFで行う。選定した2線アダプターだけで過放電・セル・温度保護が有効とはみなさない。電池108Whの80%を利用できる仮定で平均60Wなら約1.44時間だが、稼働時間1時間を確保したという判定はまだ行わない。

D5では低電圧の初期設計値を警告17.5V、制御停止要求17.0V、独立全負荷遮断16.5V、再投入可能18.0V以上＋手動ARMとする。モーターだけを切って計算機が放電を続ける構成にせず、計算機・監視部も遮断対象にする。実負荷での電圧降下、遅延、再投入、温度・セル保護の成立を検証して定数を確定する。総電圧だけでは弱いセルの過放電を検出しきれず、純正工具の保護を再現したとは扱わない。独立遮断回路と保護インターフェースは未完成で、確認前の走行は許可しない。アダプター付属30Aヒューズは今回の主幹10A設計の代わりにせず、ヒューズの型式・線材・端子を協調させる。

## 停止・再始動防止の具体構成

手持ちPico（型番・ピン有無確認待ち）をUSB接続のローカル監視器にし、UART＋3.3V RS485トランシーバで左右を制御する。**バスのマスタはPicoだけ**とし、旧USB-RS485Bを並列の第2マスタにしない。旧変換器は単体整備用へ回せるが、節約額には未計上。A/Bはツイストペアで直列配線し、両端だけの終端を基本に、モータ内蔵終端の有無を無通電実測して重複を防ぐ。信号基準は共通0Vとし、細い信号GNDをモータの電力帰路にしない。Picoは専用DC/DCから給電し、USBホストへ5Vを逆送しない電源接続にする。

| 要素 | 接続・動作 |
|---|---|
| E-stop | IDEC XA1E-BV302Rの2つのNC接点を、それぞれK1/K2のコイル給電へ直列に入れる。押下・配線断で両リレーが無励磁。ROSやPicoの処理を待たない |
| 手動ARM | TC74HC74APのD-FFを許可ラッチにする。独立した押ボタンの新しい押下エッジのみがクロック。`D=READY`。非同期クリアはE-stop、外部WD不成立、電源投入リセット、監視トリップのOR。押し続けたまま故障解除しても新しいエッジが無いので再許可しない |
| 外部WD | CD74HC123Eの再トリガ回路。5V時の出発値330kΩ／1µFで公称148.5ms。実装・温度を含む実測を120〜180msに収め、リレー開放まで200ms以下を受入値とする。5VロジックとPicoの3.3Vはレベル変換し直結を避ける |
| HB生成 | Picoの主処理が一周完了したときだけ20ms周期でGPIOを反転する。タイマPWMがCPU停止後も走り続ける作りにしない。外部WDと別にPico内蔵WDも使用する |
| コイル駆動 | 各コイルを個別トランジスタで駆動。ゲート／ベースのプルダウン、電源投入時OFF、コイル逆起電力保護を設ける。保護ダイオード等で開放が遅れる分も200msの実測に含める |
| 再許可 | 電源投入・E-stop復帰・USB再接続・内部保護復帰は全てDISARMED。ホスト指令が500ms以上ゼロ、電圧正常、E-stop解除、WD成立、ARMボタン解放確認後の新押下が必要 |

D-FFの非同期クリアと正エッジ動作、再トリガ時間式の根拠は[東芝TC74HC74](https://toshiba.semicon-storage.com/info/TC74HC74AP_datasheet_en_20140301.pdf?did=16727&prodName=TC74HC74AP)、[TI CD74HC123](https://www.ti.com/lit/ds/symlink/cd74hc123.pdf)。ボタンのデバウンス、電源投入クリア、レベル変換を含めて実装する。これらを省いてソフトウェアのフラグだけに置き換えない。完全な回路図・PCB・ファームウェアは次の製作工程で、ここには完成品の検証結果は含まれない。

起動時は車輪停止を確認し、両リレーOFFで3秒待つ。K1/K2中間点に、監視5Vから逆流防止ダイオード＋10kΩを介した微小診断電流を入れる。MOTOR_BUS側には1kΩ/1Wの放電抵抗、測定点には100kΩ/10kΩ分圧を設ける。正常なら中間点は約4.3V、バスは1V未満。K1溶着なら中間点が電池電圧へ、K2溶着ならバスの放電抵抗を介して中間点が約0.43Vへ寄る。**両接点を開いたまま中間点3〜5.5V／バス1V未満を確認**し、不成立ならARMを受け付けない。診断電流は最大約0.5mAで、モータ給電用の迂回路には使わない。実装後に部品公差・残留電圧・故障短絡で閾値を検証する。

自己検査合格後、新しいARM操作で両リレーを投入し、給電後200ms以内に速度モード・ゼロ指令・左右応答を確認してから走行指令を許す。応答が無ければ遮断・再ラッチ。NOリレーは強制ガイド接点品ではないので、検出可能な溶着と試験した故障に対応する設計として扱う。

通常は各輪へ50Hzで指令、温度取得は各輪10Hz。応答のCRC・ID・モード・指令時刻を検査する。ホスト指令が100ms古くなった場合、Picoが生きており左右応答が正常なら0.2m/s²以下でゼロまで減速し、停止確認後に遮断する。初期速度から1.0s以内に停止確認できなければ強制遮断。後期速度の解除時は期限を1.8sへ見直す。モータ応答断、Pico停止、E-stopは強制遮断経路とし、惰走を実測する。速度指令の刻みで減速度を制限し、手順書の加速度欄の単位を未確認のまま頼らない。指令が整数rpmであるため、指令ランプだけで実加速度が上限内と判定せず、無積載から測って調整する。`0xFF`の電気ブレーキは車輪を浮かせて動作確認後、低速域で用いる。ゼロ速度や電気ブレーキを停電時保持へ流用しない。

## 回生の受け先を設ける

電池・BMSが回生電流を受け入れる前提を外し、MOTOR_BUSに自立クランプを置く。K1/K2を開いた後にもモータ側へ残す。案は**LM393GN比較器＋TL431A基準＋12V小電力レギュレータ＋2SK2232＋22Ω HS50抵抗**。MOTOR_BUS自身から制御電源を取るため、Pico停止時も電圧が発生すれば動く構成である。MOSFETは抵抗をON/OFFするスイッチとして用い、線形領域に連続損失を負担させる設計にしない。

設計値はON=22.0V、OFF≈21.8V。LM393の非反転入力にバス分圧、反転入力に2.495V基準、出力から正帰還を入れる。出発値は上側78kΩ／下側10kΩ／帰還4.7MΩ、12Vへの出力プルアップ4.7kΩ、MOSFETゲート直列100Ω／プルダウン100kΩ。基準電圧・抵抗公差を含め**実装後に調整し、ON=22.0±0.2V、過渡ピーク23.5V以下**を検証する。公称抵抗値だけでこの公差を保証しない。電源デカップリング、ゲートと比較器の安定性、放熱の検証前に接続しない。[LM393メーカー資料](https://akizukidenshi.com/goodsaffix/LM393G.pdf)／[MOSFETメーカー資料](https://akizukidenshi.com/goodsaffix/2sk2232.pdf)

22V時の抵抗電流は1.0A、ON中22W。部品の50W表記は所定の放熱条件であり、トレイ取付だけで50W連続とはみなさない。候補抵抗は端子込み最大72.5×28×14.8mm、本体長49.1mm。金属面へ熱伝導材を介してねじ固定し、端子絶縁・接触ガードを設け、電池とPLAから離す。[ARCOL/Ohmiteメーカー寸法・放熱条件](https://www.ohmite.com/hs-aluminium-housed-resistors/)

総21.5kgの並進運動エネルギーは0.15m/sで0.242J、0.3m/sで0.968J。回転体・損失・制御を除いた計算なので実際の回生量ではない。平地でも減速時の回生があり、クランプと抵抗は維持する。クランプ単体試験は**約10Jパルスを10回**とし、抵抗表面60°C以下、配線・コネクタ温度上昇20K以下、バス23.5V以下を目標とする。従来の5W×60分は連続吸収の参考試験に移し、初号機の必須条件から外す。旧5°下りの2.308／4.615WはJSONの参考計算に残す。小型Pololuシャント基板への置換は今回行わず、メーカーの短時間パルス用という条件を含め、実際の減速・反復停止波形から再選定する場合の比較対象に留める。[Pololu説明](https://www.pololu.com/category/249/shunt-regulators)

バス監視が22.8Vを検出したら速度ゼロ・トリップを要求するが、ソフト監視を高速過電圧保護の代わりにしない。クランプ開放故障、抵抗断線、BMS遮断時の実挙動は未確認。抵抗を付けただけで回生保護が完成した扱いにしない。

## 2026-09-21時点の購入価格履歴と収納予算

以下は旧版の価格履歴。Pico920円は現行BOMでは0円、E-stop3,298円はAmazon3,153円へ変更し、ARM835円と主電源621円を追加した。最新購入数・小計は[現行BOM](fixed-deck/BOM.ja.md)を参照。旧表の表示価格の確認日は2026-09-21。税込・必要購入単位、送料別。購入・注文はしていない。

| 候補 | 数量／購入単位 | 表示額 | 役割・出典 |
|---|---:|---:|---|
| IDEC XA1E-BV302R | 1 | 3,298円 | 2NC、φ16.2取付。[販売元](https://www.monotaro.com/p/6051/3817/) |
| Omron G5LE-1 DC5 | 2 | 770円 | 385円/個。[RS](https://jp.rs-online.com/web/p/power-relays/0369466) |
| Raspberry Pi Pico H SC0917 | 1 | 920円 | 51×21mm基板。[秋月](https://akizukidenshi.com/catalog/g/g118085/) |
| CD74HC123E | 1 | 140円 | 外部WD。[共立](https://eleshop.jp/shop/g/gT11488/) |
| TC74HC74AP | 1 | 33円 | ARMラッチ。[共立](https://eleshop.jp/shop/g/gT11476/) |
| M78AR05-1 | 1 | 850円 | 監視専用5V/1A。主計算機へ兼用しない。[秋月](https://akizukidenshi.com/catalog/g/g113536/) |
| MAX3485ED（HTC） | 1 | 70円 | 3.3V RS485 IC、完成基板ではない。[秋月](https://akizukidenshi.com/catalog/g/g116211/) |
| ARCOL HS50 22R J | 1 | 1,033円 | 制動抵抗。[販売元](https://www.monotaro.com/g/02255191/) |
| LM393GN／TL431A | 各1 | 30＋20円 | 比較器／基準。[LM393](https://akizukidenshi.com/catalog/g/g116987/)・[TL431](https://akizukidenshi.com/catalog/g/g112018/) |
| 2SK2232／LM78L12 | 各1 | 100＋20円 | クランプFET／12V制御電源。[FET](https://akizukidenshi.com/catalog/g/g102414/)・[12V](https://akizukidenshi.com/catalog/g/g113464/) |
| SBM1060LSS | 10個パック、使用1個 | 300円 | 60V/10A逆流防止ダイオード。[秋月](https://akizukidenshi.com/catalog/g/g116378/) |
| **価格確認済み部分の小計** | | **7,584円** | 完成電装費ではない |

現行ではARMボタン本体は計上済み。デバウンス／レベル変換、電源投入リセット、コイル駆動・保護、ヒューズ類、PCB、抵抗・コンデンサ、温度・電圧測定部、放熱固定具、配線と送料は未見積。電池・充電器は選定済みで現行BOMの別カテゴリへ計上。主計算機とそのDC/DCは未選定。追加機械ブレーキは購入対象から除外し、元の小計にも入っていなかったため減額はない。上の小計から勝手に全電装費を外挿しない。旧USB変換器と専用送料5,060円の除外は[A6費用表](bom.json)に反映済みである。

D5の電装質量は電池0.680kg、アダプター0.123kg、保護・電源変換0.40kg、主計算機0.50kg、配線0.40kg、通信・監視0.05kg、合計2.153kgを見込む。旧電池0.75kg枠は置換した。これはカタログ値と配分の混在で、実測合計ではない。追加パッド・ベルト0.18kgは電装2.153kgと別に車体集計へ加え、二重に計上しない。D6では1階に電池・計算機を載せ、2階へ荷台を移す。車体全体の最新質量は[D6.9検査台帳](fixed-deck/validation.json)を参照。PCB・抵抗・リレー・固定板まで含めて実測し、重量・重心が現行の比較範囲内か確認する。10kgは厳密な上限ではなく、11.5kgを超えた場合は負荷計算を更新する。

荷台x/y±150、下面z229を避け、次をCADの**予約容積**とする。寸法はmm、`[x,y,z,Lx,Ly,Lz]`。取付台・筐体は具体未設計で、部品固定や全配線の成立を検証済みとはしない。

| 枠 | 座標・寸法 | 条件 |
|---|---|---|
| 停止・分配 | `[135,-110,112,70,70,35]` | K1/K2、ヒューズ、端子・コイル保護 |
| クランプ・変換 | `[155,-25,112,50,90,35]` | 抵抗の長手はY。金属固定面、発熱部から他基板を離す |
| E-stop＋ARM | 後方パネル中心`[-197,-103,160.4]`／`[-201,-69,160.4]` | D6.8でケースをPLA床の一体座へ載せ、上から各4本のM4で固定。片持ち脚を廃止 |
| 主電源 | 後方パネル中心`[-201,64,156.4]` | 後方電池コネクタ側。全負荷遮断。主幹端子・F0の受入確認は残る |
| Pico／通信 | `[5,65,104,70,45,30]` | RS485と監視基板の配線・USB曲げを別途確認 |

## 実機の受入試験

試験結果はまだ無い。最初は車輪を浮かせ、電流制限電源、抜け止め、回転部ガードを使う。床試験は平滑な水平床の囲われた範囲とし、初回無積載→荷物5kg→10kgへ段階的に進める。試験のために人が走行中の車体を手で止める方法は採らない。

| 試験 | 条件・記録 | 合否／解除範囲 |
|---|---|---|
| 電源・投入 | モータ端15.5/18/21V。無負荷と負荷、冷間・温間で各20回。突入電流、接点・端子電圧、バスをオシロ測定 | 接点溶着なし、導体とヒューズの許容内、バス23.5V以下。15.5Vは候補下限で、性能未確認なら運転下限を実測に合わせる |
| 再始動防止 | E-stop、USB断、Pico停止、5V消失、片輪RS485断、片輪電源断を各10回。ARM押し続け・再通電も試す | E-stop／Pico停止で接点開放200ms以内。故障解除だけでは走行再開しない。必ず新たなARM操作が必要 |
| リレー検査 | 車輪停止状態で片方のNOを仮に短絡する故障模擬を左右各1回 | 起動自己検査で検出・走行不許可。もう片方で電源分離。試験後に短絡を除去 |
| 回生回路単体 | 電流制限した注入源で約0.9A×0.5sのパルス10回。Pico給電OFFでも実施。5W×60分は任意の参考試験 | ON22.0±0.2V、バス最大23.5V、抵抗60°C以下、配線等上昇20K以下。発振・FET過熱なし。車体での反復停止時にも確認 |
| 低速連続負荷 | 左右各モータをトルク測定可能な治具で試す。無負荷から平地条件0.401N·mまで段階増加。15.5/18/21V×18.52/38.38rpmはまず各10分比較し、発熱が厳しい点と18Vの両回転端点を各60分確認。28.45rpm直進も10分比較 | 指令追従±10%以内、保護動作なし。温度70°C未満かつ最後15分の上昇2°C以下。短時間の比較だけで連続合格としない。試験した電圧・周囲温度・継続時間に範囲を限定して解除 |
| 監視閾値 | 電流・速度50Hz、温度10Hz、電圧100Hz以上で記録。温度60°Cで警告、70°Cで停止、50°C未満に冷却後手動再許可。電流の意味を実測照合 | 外部計測の支線電流は1分RMS1.25A以下を仮合否とする。車載の電流停止はモータ報告値2A超0.2秒を仮閾値とし、バス電流と同一視しない。電流内でも温度不合格なら解除しない |
| 平地停止 | 総21.5kgまで段階増加。0.15m/sの前後進・旋回中に通常停止、E-stop、ホスト断、Pico停止、片輪断を各10回。最高/最低使用電圧で実施 | 直進の停止距離0.10m以下、旋回の停止後角度変化10°以下、車輪経路0.16m以下を暫定合否。平均でなく最大値。転倒・荷物ずれ・停止後再加速なし |
| 後期速度 | 上記を0.3m/s・0.6rad/sで再実施。熱試験は37.04〜76.75rpmにも広げる | 直進停止0.30m以下。操縦・旋回・熱を含め別途解除。それまでは初期速度のまま |

低速治具での0.401N·mは、平地での加速度・転がり抵抗を含めた必要トルクに余裕1.5を掛けた比較値で、同負荷を実路面が常時与えるという意味ではない。旧坂条件0.916N·mは参考値に移し、初号機の必須熱試験には使わない。治具はローラ負荷とトルクアームなどで実負荷を測り、電流値だけでトルクを推定しない。拘束加熱試験は行わない。70°Cは報告固定子温度に対する停止値で、巻線温度との差や検出遅れを保証する値ではない。外装温度も併記する。周囲15〜35°Cを初期試験範囲とし、35°Cでの確認が未実施なら、その温度まで運転可能とは宣言しない。試験の一部を省いた場合は未実施点を残し、メーカー定格点から補間して合格にしない。

停止距離の出発点は遅れ0.2s、減速0.2m/s²の式`d=v·0.2+v²/(2·0.2)`で、0.15m/sなら0.08625m、0.3m/sなら0.285m。強制遮断の惰走がこの減速度になる保証は無いため、測定して0.10／0.30mの受入値と比較する。電気ブレーキの実減速度が構造検討値を上回る場合は、そのピークも機械側へ戻す。

## 追加機械ブレーキは不採用、初号機は平地専用

ユーザーの「ブレーキはなくていい」に従い、追加機械ブレーキは採用しない。通常のモーター減速・停止と非常停止回路は維持する。**平坦な屋内床で荷物10kgまでを設計条件とし、坂道走行・停電時の坂道保持は運用範囲に含めない。** ブレーキ購入や坂道保持試験を初号機完成の必須項目として残さない。

参考として旧総18kg・5°の必要保持力は`mg sinθ=15.385N`、タイヤ半径50.35mmで車輪合計0.7746N·m、保持余裕2で合計1.5492N·mだった。この数値はモーター制御や現在の車体が無通電保持できることを示さない。

今後坂道運用を追加する場合は、電源喪失時を含む停止・保持方法と費用を別改訂で検討する。旧坂道保持の試験案は[electrical_plan.json](electrical_plan.json)の`reference_only`に保存した。現在の合否は上表の平地停止・熱・電源・故障試験で判断する。

</details>

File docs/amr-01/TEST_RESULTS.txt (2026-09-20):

test_2kg_forward_pick_is_not_stable_in_examples (test_check_design.DesignTests.test_2kg_forward_pick_is_not_stable_in_examples) ... ok
test_budget_overrun_rejected (test_check_design.DesignTests.test_budget_overrun_rejected) ... ok
test_clockwise_polygon_rejected (test_check_design.DesignTests.test_clockwise_polygon_rejected) ... ok
test_cosmetic_exterior_not_required_but_guards_required (test_check_design.DesignTests.test_cosmetic_exterior_not_required_but_guards_required) ... ok
test_current_layout_baseline (test_check_design.DesignTests.test_current_layout_baseline) ... ok
test_current_wheel_and_caster_envelopes_fit (test_check_design.DesignTests.test_current_wheel_and_caster_envelopes_fit) ... ok
test_drive_calculation (test_check_design.DesignTests.test_drive_calculation) ... ok
test_drive_sizes_for_upper_mass_independently_of_estimate (test_check_design.DesignTests.test_drive_sizes_for_upper_mass_independently_of_estimate) ... ok
test_estimated_mass_stability_is_not_replaced_by_upper_limit (test_check_design.DesignTests.test_estimated_mass_stability_is_not_replaced_by_upper_limit) ... ok
test_frame_3030_and_stock_spares (test_check_design.DesignTests.test_frame_3030_and_stock_spares) ... ok
test_frame_must_fit_body (test_check_design.DesignTests.test_frame_must_fit_body) ... ok
test_frame_stock_and_mass_list_must_agree (test_check_design.DesignTests.test_frame_stock_and_mass_list_must_agree) ... ok
test_front_moment_ratio (test_check_design.DesignTests.test_front_moment_ratio) ... ok
test_generated_images_are_excluded (test_check_design.DesignTests.test_generated_images_are_excluded) ... ok
test_insufficient_stock_quantity_rejected (test_check_design.DesignTests.test_insufficient_stock_quantity_rejected) ... ok
test_internal_structure_is_prioritized (test_check_design.DesignTests.test_internal_structure_is_prioritized) ... ok
test_invalid_command_rpm_cap_rejected (test_check_design.DesignTests.test_invalid_command_rpm_cap_rejected) ... ok
test_invalid_geometry_rejected (test_check_design.DesignTests.test_invalid_geometry_rejected) ... ok
test_invalid_mass (test_check_design.DesignTests.test_invalid_mass) ... ok
test_json_is_strictly_serializable (test_check_design.DesignTests.test_json_is_strictly_serializable) ... ok
test_mass_budget (test_check_design.DesignTests.test_mass_budget) ... ok
test_mass_overrun_is_reported_without_clamping_estimate (test_check_design.DesignTests.test_mass_overrun_is_reported_without_clamping_estimate) ... ok
test_missing_stock_length_rejected (test_check_design.DesignTests.test_missing_stock_length_rejected) ... ok
test_no_case_is_operation_approval (test_check_design.DesignTests.test_no_case_is_operation_approval) ... ok
test_nonfinite_rejected (test_check_design.DesignTests.test_nonfinite_rejected) ... ok
test_offset_pivot_sweep (test_check_design.DesignTests.test_offset_pivot_sweep) ... ok
test_parameter_change_affects_results (test_check_design.DesignTests.test_parameter_change_affects_results) ... ok
test_purchase_cost_includes_spares_but_vehicle_mass_does_not (test_check_design.DesignTests.test_purchase_cost_includes_spares_but_vehicle_mass_does_not) ... ok
test_saved_result_matches_current_config (test_check_design.DesignTests.test_saved_result_matches_current_config) ... ok
test_selected_motor_does_not_claim_both_later_maxima (test_check_design.DesignTests.test_selected_motor_does_not_claim_both_later_maxima) ... ok
test_signed_support_distances (test_check_design.DesignTests.test_signed_support_distances) ... ok
test_small_current_requirements (test_check_design.DesignTests.test_small_current_requirements) ... ok
test_stock_length_includes_both_end_members (test_check_design.DesignTests.test_stock_length_includes_both_end_members) ... ok
test_stopping_examples (test_check_design.DesignTests.test_stopping_examples) ... ok
test_weighted_cg (test_check_design.DesignTests.test_weighted_cg) ... ok
test_zero_overturning_ratio_is_null (test_check_design.DesignTests.test_zero_overturning_ratio_is_null) ... ok

----------------------------------------------------------------------
Ran 36 tests in 0.257s

OK

2026-09-20: First CAD revalidation with base limit 10 kg / gross sizing mass 14 kg.
217 valid shapes; 67 primary parts / 2211 pairs: no nominal overlaps.
Frame 460x300; mechanical envelope 460x394x115.6 mm.
Three wheels touch Z=0; drive hardware ground clearance 26.2 mm.
CAD/BOM counts and 40 slot nuts agree.
Estimated base: 4.730 kg mechanical + 2.050 kg electrical budget = 6.780 kg.
Margin to user base limit 10 kg: 3.220 kg (estimate, not measured mass).
Sizing wheel torque with margin at gross 14 kg: 0.708 Nm.
Motor continuous duty, load ratings and component tolerances remain unverified.

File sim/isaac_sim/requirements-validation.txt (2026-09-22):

# External validators only; do not install these into Isaac Sim's environment.
numpy==2.5.3
trimesh==5.1.0
yourdfpy==0.0.60
mujoco==3.13.0
Pillow==12.3.0

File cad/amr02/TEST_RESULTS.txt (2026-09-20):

test_forward_cg_unloads_caster (test_calculate_design.MechanicalCalculationTests.test_forward_cg_unloads_caster) ... ok
test_inconsistent_geometry_and_nonfinite_inputs_rejected (test_calculate_design.MechanicalCalculationTests.test_inconsistent_geometry_and_nonfinite_inputs_rejected) ... ok
test_left_and_right_overhang_are_symmetric (test_calculate_design.MechanicalCalculationTests.test_left_and_right_overhang_are_symmetric) ... ok
test_load_at_support_has_no_beam_bending (test_calculate_design.MechanicalCalculationTests.test_load_at_support_has_no_beam_bending) ... ok
test_midspan_matches_standard_simple_beam (test_calculate_design.MechanicalCalculationTests.test_midspan_matches_standard_simple_beam) ... ok
test_more_caster_samples_converge (test_calculate_design.MechanicalCalculationTests.test_more_caster_samples_converge) ... ok
test_saved_result_and_no_implicit_operation_approval (test_calculate_design.MechanicalCalculationTests.test_saved_result_and_no_implicit_operation_approval) ... ok
test_three_wheel_forces_balance_both_moments (test_calculate_design.MechanicalCalculationTests.test_three_wheel_forces_balance_both_moments) ... ok

----------------------------------------------------------------------
Ran 8 tests in 0.124s

OK

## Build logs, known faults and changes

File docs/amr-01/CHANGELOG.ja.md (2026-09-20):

# 変更履歴

## v0.4.1 — 2026-09-20

- ユーザー指定により台車自重の上限を電池・電装込み10kgへ変更し、6kg目標を撤回。現案見込み6.78kgと上限を区別。
- 荷物2kg・将来アーム系2kgは別枠のまま、駆動力を最大構成14kgで再計算。余裕込み必要トルク約0.708N·m/輪。
- 静的感度例に台車6.78kg・10kgを追加。上限質量を現案の復元力として使わない。
- 第一案の形状・選定部品・費用は保存し、設計構造を見直す第二案は別に管理する。

## v0.4.0 — 2026-09-20

- 費用を優先してFIT0185×2、100mm駆動輪、独立軸・KP08×4、420G-R50と取付部品を選定。
- 第一案FreeCAD、STEP、実CAD画面、BOM、必要ねじ一覧、再生成・検証コードをcad/amr01へ追加。
- 確認済み部品24,409円、自加工予算34,159円、外注予算40,159円。送料・材料・加工の予算枠を明示。
- 輪距354mm、車輪幅25.4mm、キャスタートレール16mmへ更新。最高並進・旋回の同時指令は65rpm上限を超えることを明記。
- 骨格4.73kg、電装等予算込み6.78kg。6kg目標の未達と連続トルク未確認を記録。
- 生成概念画像の除外は維持。ユーザーの新指示に従い実CAD画面を保存・公開。

## v0.3.0 — 2026-09-20

Amazonで購入できる300mm・400mm材、2020の強度への懸念、3030と4040の比較、費用を考慮するというユーザー条件を反映。

- ユーザー提示のミスミNFSL6-3030を採用。300mm・400mm各4本入り1組、確認価格は税込1,467円・1,952円、商品小計3,419円。金具・板材・送料は別管理。
- 400mm材4本（外周2本＋内部補強2本）と300mm材2本を無切断で使う。組立案は長さ460×幅300mm。予備の300mm材2本は購入費に含め、機体質量には含めない。
- 商品仕様I=26,800mm⁴・0.76kg/mで再計算。使用材2.20m・1.672kg。台車の配分目標を従来上限内の6kgへ再配分。
- 支間400mm、中央荷重100Nの梁単体で3030のたわみ約0.072mm・曲げ応力約5.60MPa。軽量4040との比較を加え、現条件では3030と必要箇所の補強を採用。
- 車輪込み外形500×400mm、車輪間隔350mm、キャスター旋回軸(-150,0)を配置目標として更新。車体のみの旋回直径約789mm、外輪77.3rpm、静的支持余裕を再計算。
- 車軸x=90mm、運搬物2kg、アーム系2kg、最大構成10kgの枠は維持。参考前方姿勢での2kg把持が転倒側になる結果も維持。
- 定尺の組立外寸、購入不足、使用材との不一致、外形内への収まり、予備材の費用と質量を確認するテストを追加。生成画像は引き続き同梱しない。

## v0.2.1 — 2026-09-20

ユーザーの「外面をよくしなくていい。内部構造が大事」「画像はおかしいため上げない」という指示を反映。

- 外観を整えるための外装は不要と明記。内部構造、荷重経路、駆動系、電装配置、整備性を優先。
- 巻き込み・短絡・鋭利部などを防ぐ局所カバーは残し、意匠用外装と区別。
- 内部区画と各部の配置方針・確認事項を本文に追加。生成画像の形状・配置・二段フレームを設計値として採用しない。
- 生成画像、画像入り資料、画像参照を公開設計書と配布ZIPに収録しない。
- 外形350×280mm、台車目標5kg・上限6kg、運搬物2kg、将来アーム系2kg枠、および全ての計算用数値はv0.2から変更しない。
- 計算入力・結果の版番号と説明をv0.2.1へ更新。計算ロジックと20件の計算テストは維持。設計方針の4件も維持し、画像必須の検査を画像除外の検査へ変更。

## v0.2 — 2026-09-20

ユーザーの「前案は重すぎて家に入らない。可搬2kgでよい」という条件に合わせて概念設計を更新。

| 項目 | 旧v0.1（廃止） | 現行v0.2 |
|---|---|---|
| 運搬物 | 5kg | 2kg。アーム自重とは別 |
| 外形 | 520×420mm | 350×280mm、車輪・ガード込み |
| 台車自重 | 約18kg | 目標5kg、上限6kg |
| アーム系 | アーム10kg＋グリッパー1kg | アーム・グリッパー・専用取付/電装/電源等を合計2kg以内に仮設定 |
| 最大構成 | 通常34kg、計算枠40kg | 目標台車時9kg、上限台車時10kg |
| 床からの把持物 | 2kgを目標 | 未確定。荷台2kgの運搬と分離 |
| 主フレーム | 30角、上下二段 | 20角、低い主フレームと補強板 |
| 車輪径 | 160mm | 100mmを仮設定 |
| 車輪間隔/車軸x | 340mm / +170mm | 240mm / +90mmを仮設定 |
| キャスター | 100mm、x=-180mm | 50mm、x=-110mmを仮設定 |
| 駆動 | 車輪軸連続4N·m以上 | 車輪軸連続0.8〜1N·m級を探索目標 |
| 初期/上限速度 | 0.3 / 0.5m/s | 0.15 / 0.3m/s |
| バラスト | 低位置に標準的に確保 | 標準装備しない。配置・作業範囲を先に見直す |
| 予算 | 15万円の仮配分 | 未確定。見積金額として引き継がない |

### 追加した事項

重量目標5kgを区分別に配分。外形と旋回包絡を分離し、車体のみで約599mmの旋回直径を計算。台車5kg・6kgで静的安定性を再計算し、仮の前方姿勢では2kg把持が転倒側になる点を明記。

入力値を`design_parameters.json`へ分離。把持上限は`null`とし、感度計算の物体質量を把持許可値と誤認させない。全姿勢・動的安定性・実機安全性は未検証。

旧版にあった「30角が必須」「大型アームに備える」「床2kgを拾う」といった前提を現行必須条件として引き継がない。過去の把持能力に関する記述よりも、今回の小型軽量化と未確定事項の分離を優先した。

旧版ファイルは変更せず履歴として残し、現行版を`amr_v0_2`として別管理する。

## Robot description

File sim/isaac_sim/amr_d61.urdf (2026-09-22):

<?xml version='1.0' encoding='utf-8'?>
<robot name="amr_d61">
  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
  <link name="left_wheel_link">
    <inertial>
      <origin xyz="2.68715937167e-07 0.000842844210193 -1.43130870062e-06" rpy="0 0 0" />
      <mass value="0.45" />
      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
    </inertial>
    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
  </link>
  <link name="base_link">
    <inertial>
      <origin xyz="-0.0934123624767 -0.000838661994572 0.0806849806437" rpy="0 0 0" />
      <mass value="8.87086255317" />
      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
    </inertial>
    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
  </link>
  <link name="right_wheel_link">
    <inertial>
      <origin xyz="-2.68715937167e-07 -0.000842844210193 -1.43130870061e-06" rpy="0 0 0" />
      <mass value="0.45" />
      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
    </inertial>
    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
  </link>
  <link name="caster_swivel_link">
    <inertial>
      <origin xyz="-0.00208368833284 3.45547710101e-19 -0.0060383207606" rpy="0 0 0" />
      <mass value="0.0887160418696" />
      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
    </inertial>
    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
  </link>
  <link name="caster_wheel_link">
    <inertial>
      <origin xyz="2.84217094304e-17 2.29472925463e-19 0" rpy="0 0 0" />
      <mass value="0.035507350075" />
      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
    </inertial>
    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
  </link>
  <joint name="left_wheel_joint" type="continuous">
    <parent link="base_link" />
    <child link="left_wheel_link" />
    <origin xyz="0 0.1745 0" rpy="0 0 0" />
    <axis xyz="0 1 0" />
    <limit effort="0.96" velocity="12.0427718388" />
    <dynamics damping="0" friction="0" />
  </joint>
  <joint name="right_wheel_joint" type="continuous">
    <parent link="base_link" />
    <child link="right_wheel_link" />
    <origin xyz="0 -0.1745 0" rpy="0 0 0" />
    <axis xyz="0 1 0" />
    <limit effort="0.96" velocity="12.0427718388" />
    <dynamics damping="0" friction="0" />
  </joint>
  <joint name="caster_swivel_joint" type="continuous">
    <parent link="base_link" />
    <child link="caster_swivel_link" />
    <origin xyz="-0.24 0 0.00765" rpy="0 0 0" />
    <axis xyz="0 0 1" />
    <limit effort="0" velocity="30" />
    <dynamics damping="0" friction="0" />
  </joint>
  <joint name="caster_wheel_joint" type="continuous">
    <parent link="caster_swivel_link" />
    <child link="caster_wheel_link" />
    <origin xyz="-0.016 0 -0.033" rpy="0 0 0" />
    <axis xyz="0 1 0" />
    <limit effort="0" velocity="30" />
    <dynamics damping="0" friction="0" />
  </joint>
</robot>

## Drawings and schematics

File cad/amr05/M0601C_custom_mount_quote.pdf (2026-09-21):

# M0601C_111 専用モータ金具 — 見積用寸法図

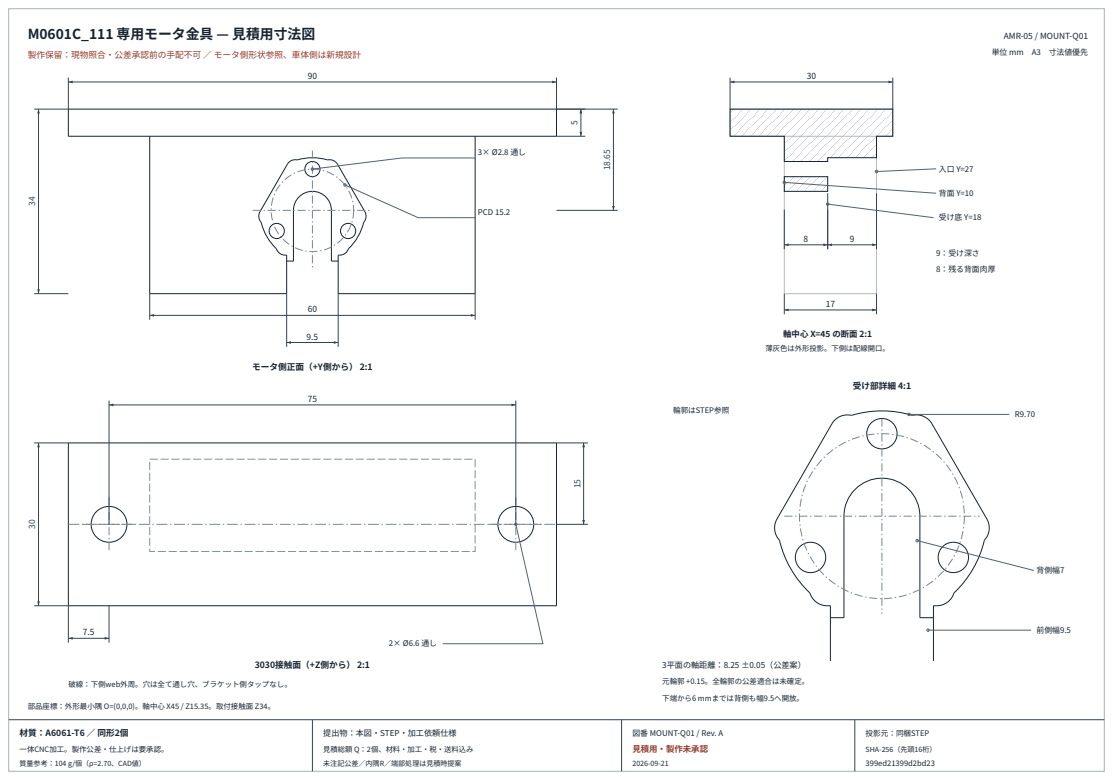
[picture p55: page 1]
モータ側正面（+Y側から） 2:1; PCD 15.2; 軸中心 X=45 の断面 2:1 薄灰色は外形投影。下側は配線開口。; 受け底 Y=18; 9：受け深さ 8：残る背面肉厚; 3030接触面（+Z側から） 2:1; 受け部詳細 4:1; 背側幅7; 前側幅9.5; 輪郭はSTEP参照; 3平面の軸距離：8.25 ±0.05（公差案）; 元輪郭 +0.15。全輪郭の公差適合は未確定。 下端から6 mmまでは背側も幅9.5へ開放。; 投影元：同梱STEP; SHA-256（先頭16桁） 399ed21399d2bd23

AMR-05 / MOUNT-Q01
単位 mm　A3　寸法値優先

製作保留：現物照合・公差承認前の手配不可 ／ モータ側形状参照、車体側は新規設計

破線：下側web外周。穴は全て通し穴、ブラケット側タップなし。

部品座標：外形最小隅 O=(0,0,0)。軸中心 X45 / Z15.35。取付接触面 Z34。

一体CNC加工。製作公差・仕上げは要承認。
質量参考：104 g/個（ρ=2.70、CAD値）

提出物：本図・STEP・加工依頼仕様
見積総額 Q：2個、材料・加工・税・送料込み
未注記公差／内隅R／端部処理は見積時提案

図番 MOUNT-Q01 / Rev. A
見積用・製作未承認

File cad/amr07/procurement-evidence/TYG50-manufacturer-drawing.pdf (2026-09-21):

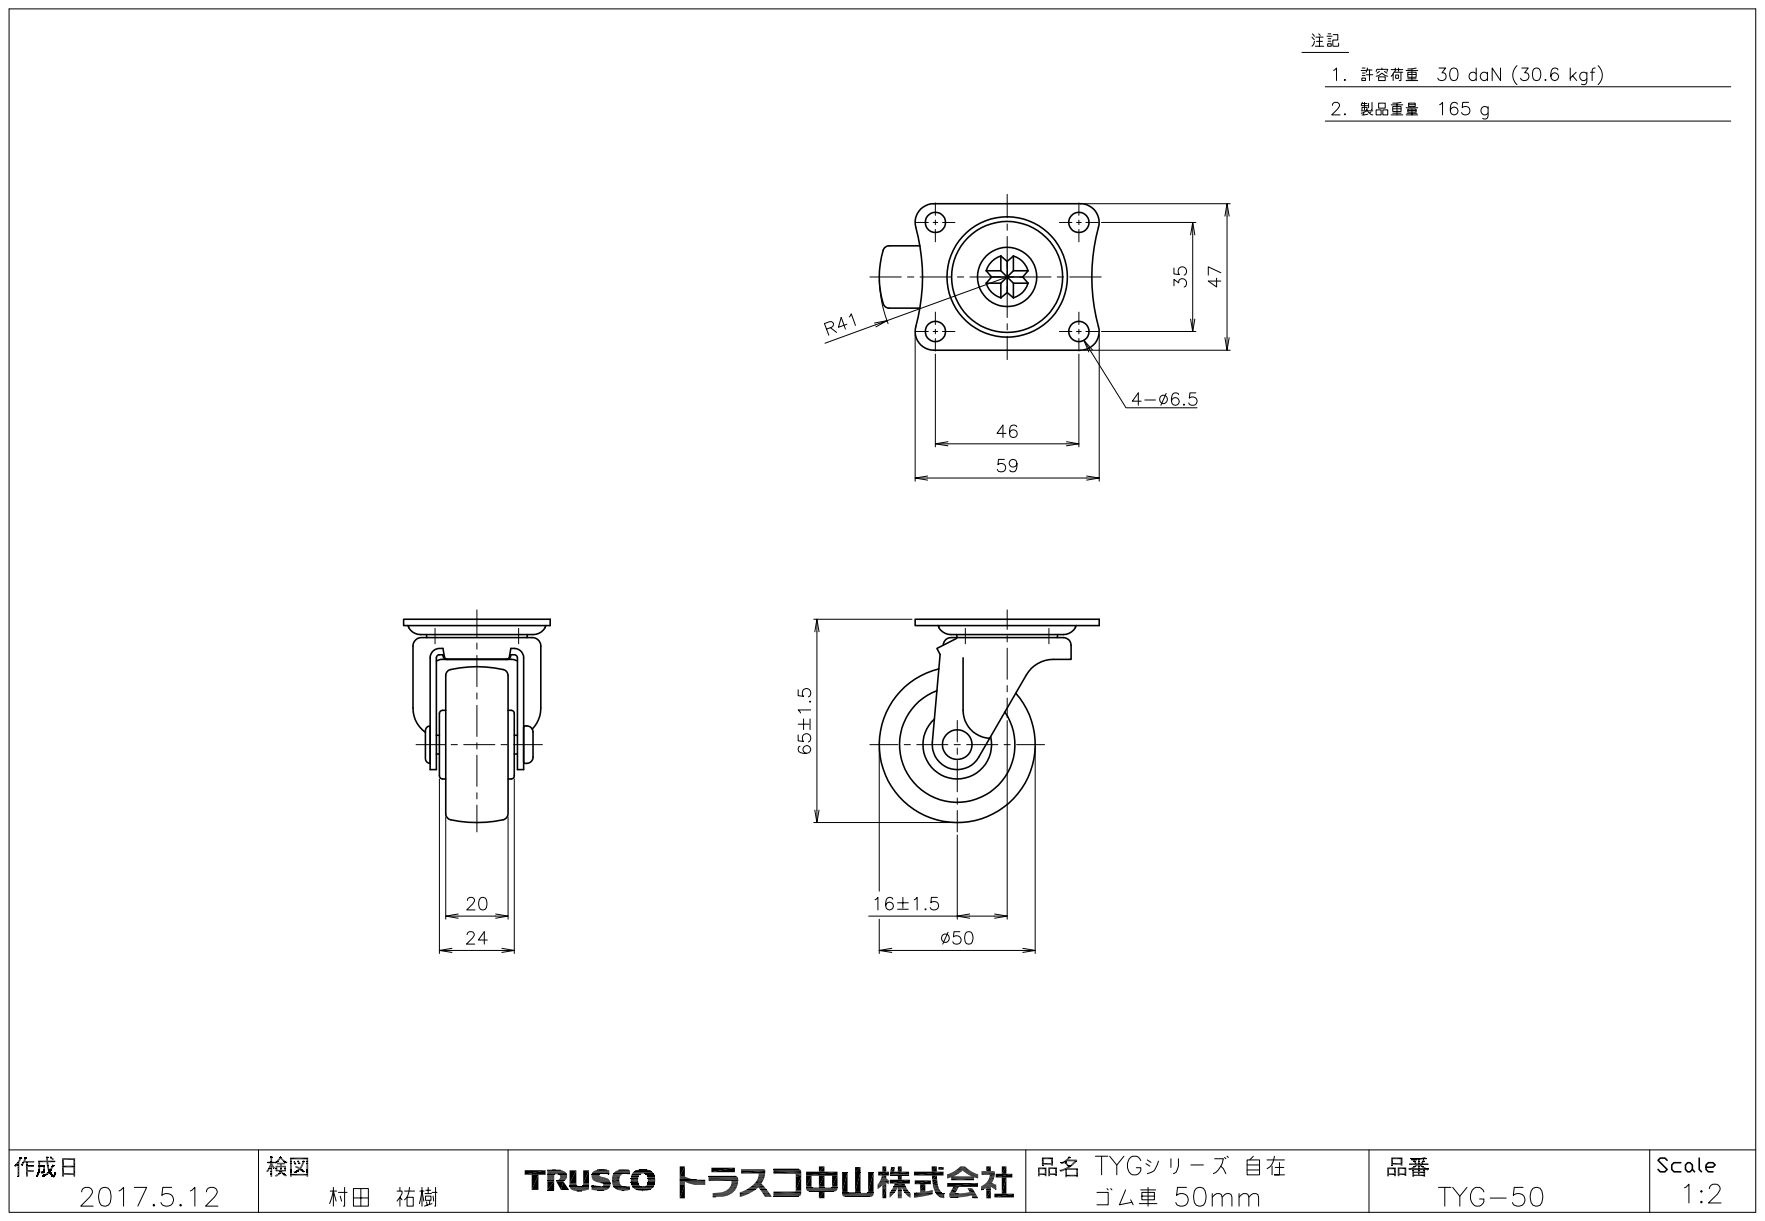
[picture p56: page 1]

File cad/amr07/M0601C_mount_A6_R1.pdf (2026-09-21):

# M0601C_111 金具 A6-R1 — 機能公差修正版

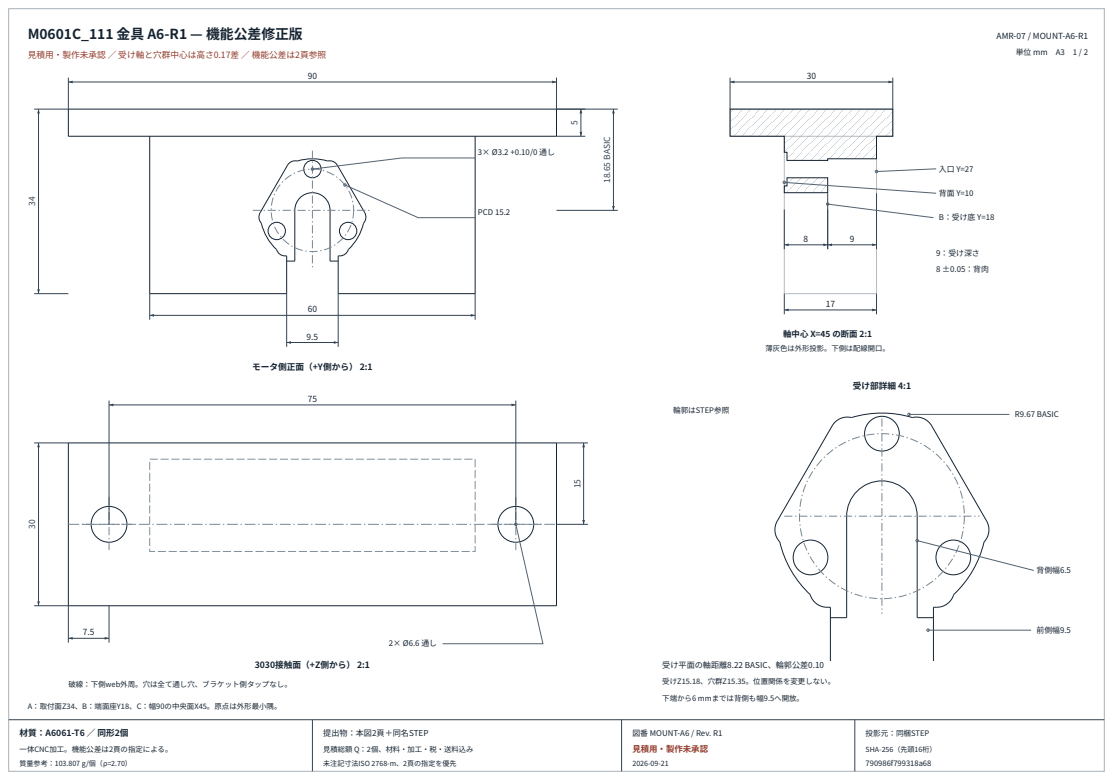
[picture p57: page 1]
見積用・製作未承認 ／ 受け軸と穴群中心は高さ0.17差 ／ 機能公差は2頁参照; AMR-07 / MOUNT-A6-R1 単位 mm A3 1 / 2; モータ側正面（+Y側から） 2:1; 18.65 BASIC; PCD 15.2; 軸中心 X=45 の断面 2:1 薄灰色は外形投影。下側は配線開口。; B：受け底 Y=18; 9：受け深さ 8 ±0.05：背肉; 3030接触面（+Z側から） 2:1; 受け部詳細 4:1; R9.67 BASIC; 背側幅6.5; 前側幅9.5; 輪郭はSTEP参照; 受け平面の軸距離8.22 BASIC、輪郭公差0.10; 受けZ15.18、穴群Z15.35。位置関係を変更しない。 下端から6 mmまでは背側も幅9.5へ開放。; A：取付面Z34、B：端面座Y18、C：幅90の中央面X45。原点は外形最小隅。; 一体CNC加工。機能公差は2頁の指定による。 質量参考：103.807 g/個（ρ=2.70）; 投影元：同梱STEP; SHA-256（先頭16桁） 790986f799318a68

破線：下側web外周。穴は全て通し穴、ブラケット側タップなし。

提出物：本図2頁＋同名STEP
見積総額 Q：2個、材料・加工・税・送料込み
未注記寸法ISO 2768-m、2頁の指定を優先

図番 MOUNT-A6 / Rev. R1
見積用・製作未承認

M0601C_111 金具 A6-R1 — 機能公差・検査基準 | 2 / 2

同形2個、A6061-T6、生地、タップなし。自動見積用。購入ロットの現物照合・強度試験前は製作未承認。

### データムと公差（寸法単位 mm。BASIC は理論的に正確な寸法）

対象 | 指定 | 検査・適用
基準 A | 3030接触平面 Z34：平面度0.05 | 一次データム、取り付け面
基準 B | モータ端面座 Y18：平面度0.05、直角度0.05 | A | 二次データム、受け底の実接触面
基準 C | 外形X0/X90の対向面から導く中央面 X45 | 三次データム。左右の原点を共通化
受け全輪郭 | 面の輪郭度0.10 | A | B | C、対称配置 ±0.05 | 形状と位置を含む総合公差。円弧だけ除外しない
輪郭基本寸法 | 受け中心 X45/Z15.18、R9.67、平面軸距離8.22 | 6小円弧R1.62、全輪郭はSTEP BASIC
穴群の位置 | 3×Ø3.2 +0.10/0、位置度 Ø0.10 | A | B | C | 材料長8、全通し。PCD15.2 BASIC
穴群 X/Z BASIC | (45,22.95)、(38.418207,11.55)、(51.581793,11.55) | 群中心X45/Z15.35。受け中心から+0.17
背肉／受け深さ | 8 ±0.05 (Y10…18) ／ 9 ±0.10 (Y18…27) | 端面座Bと背面の平行度0.05
小ねじ頭側座ぐり | 3×Ø6.2 +0.10/0、深0.50±0.05、中心は各穴と同じ | 位置度Ø0.10 | A | B | C、底面平行度0.05 | B
3030通し穴 | 2×Ø6.6 +0.20/0、X/Y=(7.5,15),(82.5,15) | フランジ5±0.10。溝に沿う位置は±0.20

輪郭度は切欠き以外の受け壁に適用。背側配線幅6.5±0.10、前・下端9.5は一般公差。R9.67に別の位置誤差±0.05を加算しない。
データムA/Bを侵す面取り不可。バリ取りC0.1以下。M6頭側はC0.3±0.1。厚い皮膜なし。 web根元は元A4同様。形状に影響する工具Rは提案・再審査。全体へ±0.05を一律指定するものではない。

### 組付け条件と公差の使い方（完成機の許容荷重・安全率を証明する記載ではない）

1. 公称モータ軸Z15.35、受け軸Z15.18。タイヤ反力側の輪郭（車体+Z）へボスを着座させて端面を締結。
2. 公表ボスØ18.85…19.05／平面距離7.85…8.15の条件で着座量0.04…0.295、穴群中心から−0.130…+0.125。
3. 金具孔位置半径0.05＋実モータ孔群偏心0.05以下を受入条件とする。モータ側0.05は未確認の条件。
4. 最大中心差0.130+0.10=0.230 < (3.2−2.5)/2=0.350。片側余裕0.120は上記条件が成立した場合のみ。
5. M2.5×12＋小径座金t0.5、座ぐり底背肉7.5で公称ねじ込み4。首元・座金・穴底を現物確認。
6. 3本の同時挿入、荷重側輪郭接触、端面/頭/座金の全周座り、配線φ6予約を確認。全面同時接触とは仮定しない。
7. 装着高さ・タイヤの荷重たわみを測り、キャスター接地を再調整。CAD公称接地0は現物の高さ保証ではない。
8. 材質証明、ねじ規格、実ナット/フレーム溝寸法、接触・ねじ山・溝縁の荷重確認後に製作/運用を判断。

比較基準：A4 幅90/厚5/孔ピッチ75を維持。D5幅75/厚6は価格低減せず、今回の採用対象から外す。

引用元の motor STEP / メーカー寸法図 / 公開ブラケット輪郭は MOUNT_INTERFACE_REVIEW.ja.md を参照。

MOUNT-A6 / Rev. R1 / 見積用・製作未承認 / 2026-09-21

STEP SHA-256: 790986f799318a681d220ad8c6d4676e5f879409067c87b8af5ff7fc0ccc039d

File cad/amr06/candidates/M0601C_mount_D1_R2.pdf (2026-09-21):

# M0601C_111 金具 D1 — 見積用寸法図

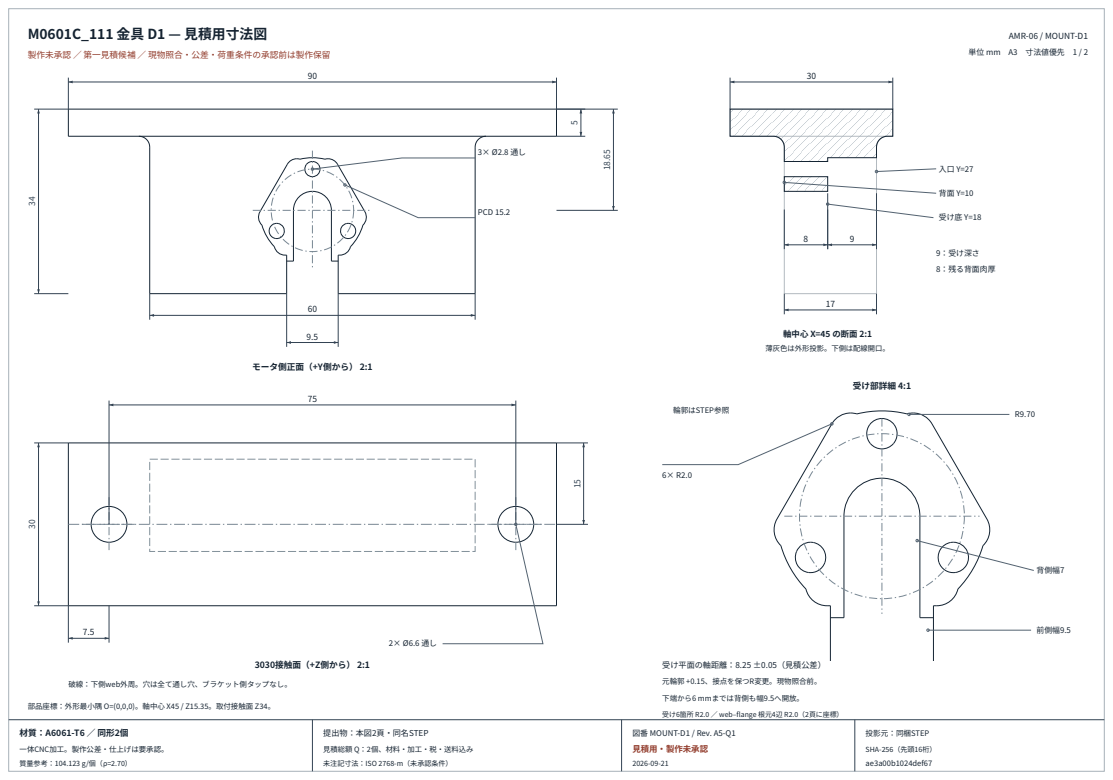
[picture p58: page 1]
AMR-06 / MOUNT-D1; モータ側正面（+Y側から） 2:1; PCD 15.2; 軸中心 X=45 の断面 2:1 薄灰色は外形投影。下側は配線開口。; 受け底 Y=18; 9：受け深さ 8：残る背面肉厚; 3030接触面（+Z側から） 2:1; 受け部詳細 4:1; 背側幅7; 前側幅9.5; 輪郭はSTEP参照; 投影元：同梱STEP; SHA-256（先頭16桁） ae3a00b1024def67

製作未承認 ／ 第一見積候補 ／ 現物照合・公差・荷重条件の承認前は製作保留

単位 mm　A3　寸法値優先　1 / 2

受け平面の軸距離：8.25 ±0.05（見積公差）
元輪郭 +0.15、接点を保つR変更。現物照合前。
下端から6 mmまでは背側も幅9.5へ開放。
受け6箇所 R2.0 ／ web–flange 根元4辺 R2.0（2頁に座標）
図番 MOUNT-D1 / Rev. A5-Q1
見積用・製作未承認

破線：下側web外周。穴は全て通し穴、ブラケット側タップなし。

部品座標：外形最小隅 O=(0,0,0)。軸中心 X45 / Z15.35。取付接触面 Z34。

一体CNC加工。製作公差・仕上げは要承認。
質量参考：104.123 g/個（ρ=2.70）

提出物：本図2頁・同名STEP
見積総額 Q：2個、材料・加工・税・送料込み
未注記寸法：ISO 2768-m（未承認条件）

M0601C_111 金具 D1 — 加工条件・機能寸法・比較記録 | Rev. A5-Q1　2 / 2

製作未承認：この資料は見積比較用。安全率2、全輪郭のはめあい、公差累積、加工工程の成立を認定しない。

### 見積条件（A4と同じ公差範囲）

項目 | 指定・依頼内容
数量・材質・処理 | 同形2個、A6061-T6、表面処理なし。左右用は同じ部品。製造10日の比較条件、納期確約ではない。
特別公差 | 受け平面の軸距離8.25 ±0.05 mmのみ。穴位置やRへ新たな±0.05指定を追加していない。
その他の寸法 | ISO 2768-mを見積条件とする。幾何公差・穴位置・全輪郭適合は現物ロット確認後に決める。
仕上げ・形状変更 | バリ取り。接触平面・受け深さ・ねじ座面を削らない。STEP輪郭や内隅Rの変更は製作前に要確認。

### 部品座標と加工対象（形状は同名STEP、1頁の実投影を参照）

O=外形最小隅。車体座標から(45,120,35) mmを引いた座標。軸X45/Z15.35、3030接触面Z34。

対象 | 局所座標・寸法 mm | 注記
外形／根元 | 90×30×34、flange t5、web60×17 | 4凹エッジの根元R2.0
受け／背肉 | 前面Y27、底Y18、背面Y10 | 受け深さ9、背肉8
根元4辺 | Z29：X15/75のY10…27、Y10/27のX15…75 | 全4辺 R2.0、肉を追加する丸み
受け輪郭 | 大円弧R9.70、6小円弧R2.0、軸距離8.25 ±0.05 | 接点を保ち小円弧中心を移動
モータ穴 | 3×Ø2.8、PCD15.2、材料内長8（Y10…18） | 全通し穴、タップなし
モータ穴 X/Z | (38.4182,11.55)、(45,22.95)、(51.5818,11.55) | CAD座標参照値、追加の公差指定ではない
3030穴 X/Y | 2×Ø6.6：(7.5,15)、(82.5,15)、pitch75 | 材料内長5（Z29…34）、全通し
ケーブル開口 | 背側幅7、前側と下端Z0…6は幅9.5 | 背側のM2.5頭座面を残す

### 変更前A4からの幾何比較（加工費・荷重性能の保証値ではない）

計測項目 | D1 の値 | 解釈・限界
支持平面の有効長 | 斜め2面：各10.117806、下側：0.308903×2片 | 全4片を維持。下側を同等の第3支持面としない
R9.70円弧の有効長 | 3箇所：各4.659879、A4比81.9% | 隙間ばめ。全壁の同時全面接触は未確認
追加／除去体積 mm³ | 根元追加135.262582 ／ 受け除去11.890890 | 背肉減少0、5穴・外形を維持。1 solid / valid
質量／候補の扱い | 104.123 g/個、ρ=2.70 g/cm³ | 第一見積候補

CADの公称形状と製造工具の選定は別。CAM、実公差、実機接触、輪荷重・横力、車体干渉は別途確認する。 回り止めの平面・円弧を残す設計。M2.5の3本だけへ全荷重を逃がす仕様ではない。現物照合と強度確認前は製作保留。

投影・座標元：M0601C_mount_D1_R2.step
STEP SHA-256：ae3a00b1024def670b45e712af563593250c1be6d38595254ef27471f37b7e8b

AMR-06 / MOUNT-D1 / Rev. A5-Q1
単位 mm。寸法値優先。A4原本・旧見積から独立したA5候補。

2026-09-21
見積用・製作未承認

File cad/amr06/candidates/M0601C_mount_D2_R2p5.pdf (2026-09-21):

# M0601C_111 金具 D2 — 見積用寸法図

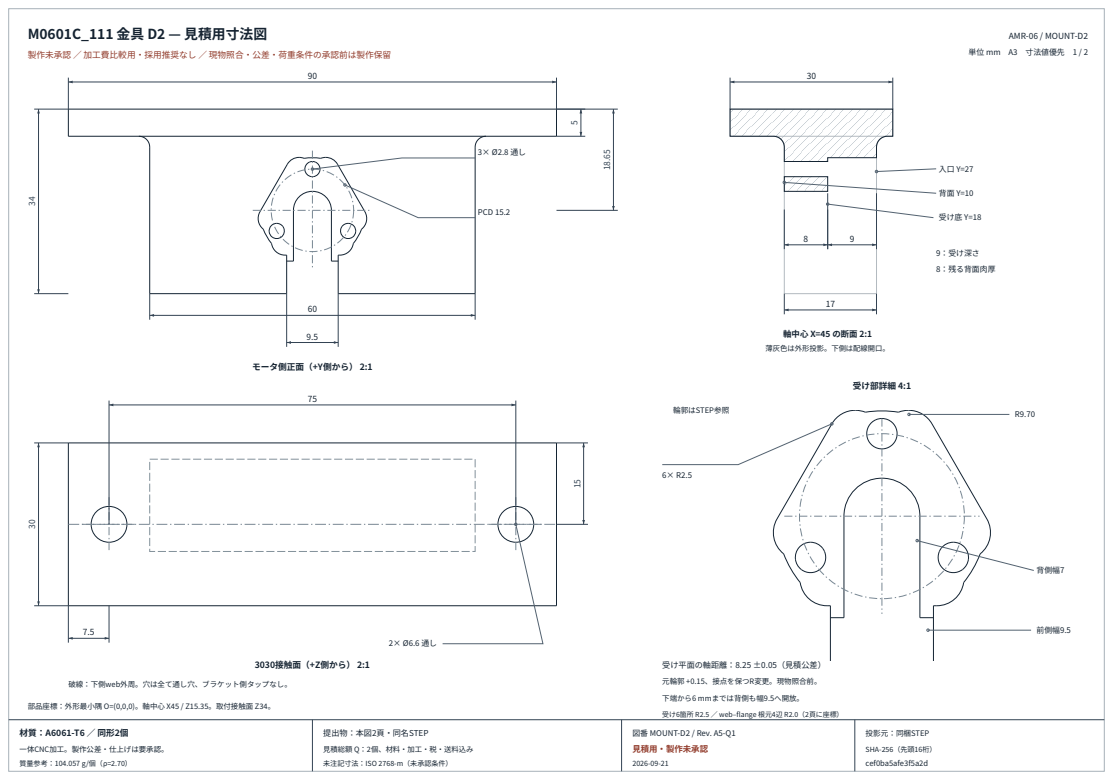
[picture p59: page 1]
AMR-06 / MOUNT-D2; モータ側正面（+Y側から） 2:1; PCD 15.2; 軸中心 X=45 の断面 2:1 薄灰色は外形投影。下側は配線開口。; 受け底 Y=18; 9：受け深さ 8：残る背面肉厚; 3030接触面（+Z側から） 2:1; 受け部詳細 4:1; 背側幅7; 前側幅9.5; 輪郭はSTEP参照; 投影元：同梱STEP; SHA-256（先頭16桁） cef0ba5afe3f5a2d

製作未承認 ／ 加工費比較用・採用推奨なし ／ 現物照合・公差・荷重条件の承認前は製作保留

単位 mm　A3　寸法値優先　1 / 2

受け平面の軸距離：8.25 ±0.05（見積公差）
元輪郭 +0.15、接点を保つR変更。現物照合前。
下端から6 mmまでは背側も幅9.5へ開放。
受け6箇所 R2.5 ／ web–flange 根元4辺 R2.0（2頁に座標）
図番 MOUNT-D2 / Rev. A5-Q1
見積用・製作未承認

破線：下側web外周。穴は全て通し穴、ブラケット側タップなし。

部品座標：外形最小隅 O=(0,0,0)。軸中心 X45 / Z15.35。取付接触面 Z34。

一体CNC加工。製作公差・仕上げは要承認。
質量参考：104.057 g/個（ρ=2.70）

提出物：本図2頁・同名STEP
見積総額 Q：2個、材料・加工・税・送料込み
未注記寸法：ISO 2768-m（未承認条件）

M0601C_111 金具 D2 — 加工条件・機能寸法・比較記録 | Rev. A5-Q1　2 / 2

製作未承認：この資料は見積比較用。安全率2、全輪郭のはめあい、公差累積、加工工程の成立を認定しない。

### 見積条件（A4と同じ公差範囲）

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

### 部品座標と加工対象（形状は同名STEP、1頁の実投影を参照）

O=外形最小隅。車体座標から(45,120,35) mmを引いた座標。軸X45/Z15.35、3030接触面Z34。

対象 | 局所座標・寸法 mm | 注記
外形／根元 | 90×30×34、flange t5、web60×17 | 4凹エッジの根元R2.0
受け／背肉 | 前面Y27、底Y18、背面Y10 | 受け深さ9、背肉8
根元4辺 | Z29：X15/75のY10…27、Y10/27のX15…75 | 全4辺 R2.0、肉を追加する丸み
受け輪郭 | 大円弧R9.70、6小円弧R2.5、軸距離8.25 ±0.05 | 接点を保ち小円弧中心を移動
モータ穴 | 3×Ø2.8、PCD15.2、材料内長8（Y10…18） | 全通し穴、タップなし
モータ穴 X/Z | (38.4182,11.55)、(45,22.95)、(51.5818,11.55) | CAD座標参照値、追加の公差指定ではない
3030穴 X/Y | 2×Ø6.6：(7.5,15)、(82.5,15)、pitch75 | 材料内長5（Z29…34）、全通し
ケーブル開口 | 背側幅7、前側と下端Z0…6は幅9.5 | 背側のM2.5頭座面を残す

### 変更前A4からの幾何比較（加工費・荷重性能の保証値ではない）

計測項目 | D2 の値 | 解釈・限界
支持平面の有効長 | 斜め2面：各10.117806、下側：0.308903×2片 | 全4片を維持。下側を同等の第3支持面としない
R9.70円弧の有効長 | 3箇所：各3.065366、A4比53.9% | 隙間ばめ。全壁の同時全面接触は未確認
追加／除去体積 mm³ | 根元追加135.262582 ／ 受け除去36.271047 | 背肉減少0、5穴・外形を維持。1 solid / valid
質量／候補の扱い | 104.057 g/個、ρ=2.70 g/cm³ | 円弧約54%の加工費比較案。採用推奨なし

CADの公称形状と製造工具の選定は別。CAM、実公差、実機接触、輪荷重・横力、車体干渉は別途確認する。 回り止めの平面・円弧を残す設計。M2.5の3本だけへ全荷重を逃がす仕様ではない。現物照合と強度確認前は製作保留。

投影・座標元：M0601C_mount_D2_R2p5.step
STEP SHA-256：cef0ba5afe3f5a2dbe5f3a8c1b49d430de055787959de092d774c015d3121c05

AMR-06 / MOUNT-D2 / Rev. A5-Q1
単位 mm。寸法値優先。A4原本・旧見積から独立したA5候補。

2026-09-21
見積用・製作未承認

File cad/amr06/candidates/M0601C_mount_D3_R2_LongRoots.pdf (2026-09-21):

# M0601C_111 金具 D3 — 見積用寸法図

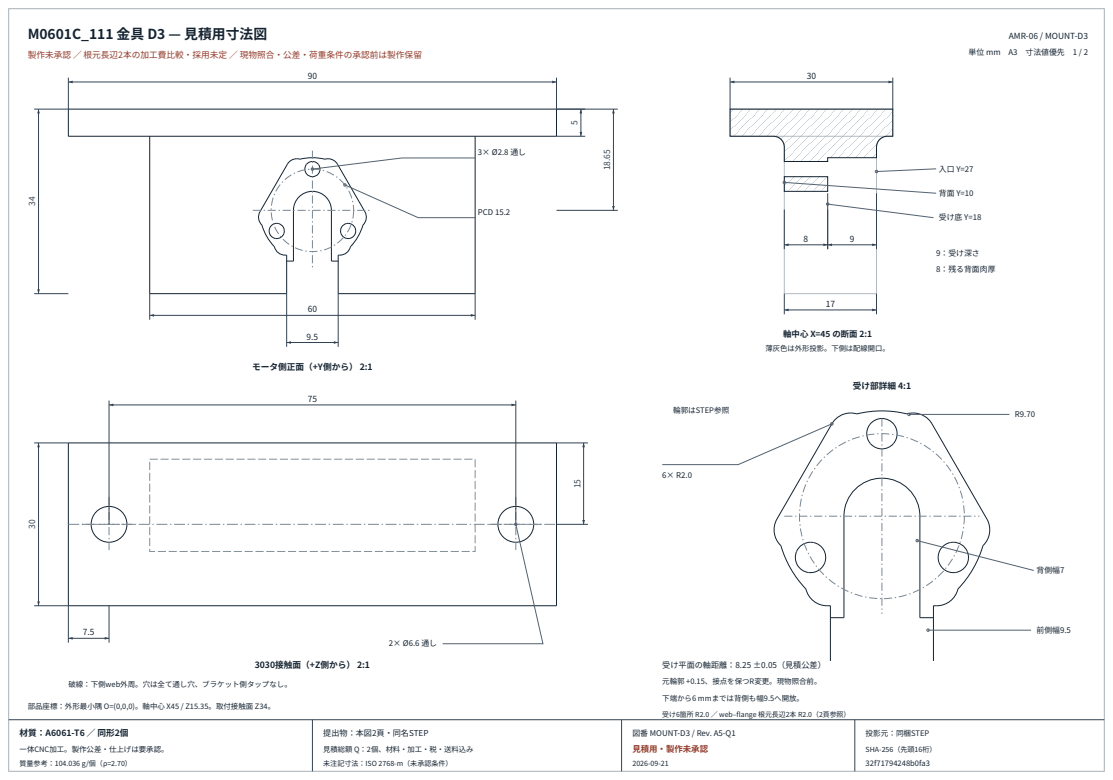
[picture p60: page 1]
AMR-06 / MOUNT-D3; モータ側正面（+Y側から） 2:1; PCD 15.2; 軸中心 X=45 の断面 2:1 薄灰色は外形投影。下側は配線開口。; 受け底 Y=18; 9：受け深さ 8：残る背面肉厚; 3030接触面（+Z側から） 2:1; 受け部詳細 4:1; 背側幅7; 前側幅9.5; 輪郭はSTEP参照; 投影元：同梱STEP; SHA-256（先頭16桁） 32f71794248b0fa3

製作未承認 ／ 根元長辺2本の加工費比較・採用未定 ／ 現物照合・公差・荷重条件の承認前は製作保留

単位 mm　A3　寸法値優先　1 / 2

受け平面の軸距離：8.25 ±0.05（見積公差）
元輪郭 +0.15、接点を保つR変更。現物照合前。
下端から6 mmまでは背側も幅9.5へ開放。
受け6箇所 R2.0 ／ web–flange 根元長辺2本 R2.0（2頁参照）
図番 MOUNT-D3 / Rev. A5-Q1
見積用・製作未承認

破線：下側web外周。穴は全て通し穴、ブラケット側タップなし。

部品座標：外形最小隅 O=(0,0,0)。軸中心 X45 / Z15.35。取付接触面 Z34。

一体CNC加工。製作公差・仕上げは要承認。
質量参考：104.036 g/個（ρ=2.70）

提出物：本図2頁・同名STEP
見積総額 Q：2個、材料・加工・税・送料込み
未注記寸法：ISO 2768-m（未承認条件）

M0601C_111 金具 D3 — 加工条件・機能寸法・比較記録 | Rev. A5-Q1　2 / 2

製作未承認：この資料は見積比較用。安全率2、全輪郭のはめあい、公差累積、加工工程の成立を認定しない。

### 見積条件（A4と同じ公差範囲）

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

### 部品座標と加工対象（形状は同名STEP、1頁の実投影を参照）

O=外形最小隅。車体座標から(45,120,35) mmを引いた座標。軸X45/Z15.35、3030接触面Z34。

対象 | 局所座標・寸法 mm | 注記
外形／根元 | 90×30×34、flange t5、web60×17 | X方向長辺2本だけR2.0
受け／背肉 | 前面Y27、底Y18、背面Y10 | 受け深さ9、背肉8
根元 | Z29：Y10/27のX15…75、長さ60×2辺 | 端辺X15/75はA4同様、R追加なし
受け輪郭 | 大円弧R9.70、6小円弧R2.0、軸距離8.25 ±0.05 | 接点を保ち小円弧中心を移動
モータ穴 | 3×Ø2.8、PCD15.2、材料内長8（Y10…18） | 全通し穴、タップなし
モータ穴 X/Z | (38.4182,11.55)、(45,22.95)、(51.5818,11.55) | CAD座標参照値、追加の公差指定ではない
3030穴 X/Y | 2×Ø6.6：(7.5,15)、(82.5,15)、pitch75 | 材料内長5（Z29…34）、全通し
ケーブル開口 | 背側幅7、前側と下端Z0…6は幅9.5 | 背側のM2.5頭座面を残す

### 変更前A4からの幾何比較（加工費・荷重性能の保証値ではない）

計測項目 | D3 の値 | 解釈・限界
支持平面の有効長 | 斜め2面：各10.117806、下側：0.308903×2片 | 全4片を維持。下側を同等の第3支持面としない
R9.70円弧の有効長 | 3箇所：各4.659879、A4比81.9% | 隙間ばめ。全壁の同時全面接触は未確認
追加／除去体積 mm³ | 根元追加103.008882 ／ 受け除去11.890890 | 背肉減少0、5穴・外形を維持。1 solid / valid
質量／候補の扱い | 104.036 g/個、ρ=2.70 g/cm³ | 根元長辺2本の加工費比較・採用未定

CADの公称形状と製造工具の選定は別。CAM、実公差、実機接触、輪荷重・横力、車体干渉は別途確認する。 回り止めの平面・円弧を残す設計。M2.5の3本だけへ全荷重を逃がす仕様ではない。現物照合と強度確認前は製作保留。

投影・座標元：M0601C_mount_D3_R2_LongRoots.step
STEP SHA-256：32f71794248b0fa3c10abdeae57ba4aa564fbf5404662bab1d4b3d5644849ac9

AMR-06 / MOUNT-D3 / Rev. A5-Q1
単位 mm。寸法値優先。A4原本・旧見積から独立したA5候補。

2026-09-21
見積用・製作未承認

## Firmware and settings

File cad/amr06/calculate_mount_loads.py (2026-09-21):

"""Reproducible A5 load comparisons using only Python's standard library.

This is not FEA, a material/fastener qualification, or operating approval.
Run normally to write load_calculations.json; --check-only writes no files.
"""
from pathlib import Path
import argparse
import json
import math

HERE = Path(__file__).resolve().parent


def cross(a, b):
    return [a[1]*b[2]-a[2]*b[1], a[2]*b[0]-a[0]*b[2],
            a[0]*b[1]-a[1]*b[0]]


def add(*vectors):
    return [sum(v[i] for v in vectors) for i in range(3)]


def scale(vector, factor):
    return [factor*x for x in vector]


def wrench_residual(forces_at_points, expected_force, expected_moment):
    force = add(*(f for _, f in forces_at_points))
    moment = add(*(cross(p, f) for p, f in forces_at_points))
    return {
        "force_N": max(abs(force[i]-expected_force[i]) for i in range(3)),
        "moment_Nmm": max(abs(moment[i]-expected_moment[i]) for i in range(3)),
    }


def validate_inputs(c):
    def finite(value):
        if isinstance(value, dict):
            for x in value.values():
                finite(x)
        elif isinstance(value, list):
            for x in value:
                finite(x)
        elif isinstance(value, (int, float)) and not isinstance(value, bool):
            if not math.isfinite(value):
                raise ValueError("Non-finite numeric input")
    finite(c)
    geo, mount = c["geometry"], c["mount"]
    positive = [c["gravity_m_s2"], c["mass"]["base_upper_mass_kg"],
                c["mass"]["payload_kg"], geo["drive_track_mm"],
                geo["wheel_diameter_mm"], mount["flange_thickness_mm"],
                mount["motor_PCD_mm"], mount["frame_bolt_pitch_x_mm"],
                c["stiffness"]["elastic_modulus_assumed_MPa"],
                *mount["frame_contact_arm_sensitivity_mm"],
                *mount["gross_section_width_sensitivity_mm"]]
    if min(positive) <= 0:
        raise ValueError("Masses, geometry and stiffness inputs must be positive")
    if c["strength"]["static_safety_factor_target"] < 1:
        raise ValueError("Safety factor target must be >= 1")
    n = geo["caster_orientation_samples"]
    if not isinstance(n, int) or n < 4:
        raise ValueError("At least four integer caster samples required")
    if min(c["strength"]["lateral_force_over_vertical_sensitivity"]) < 0:
        raise ValueError("This comparison uses positive-outboard lateral ratios")
    if not math.isclose(mount["rear_wall_mm"]+mount["seat_depth_mm"],
                        mount["web_thickness_mm"]):
        raise ValueError("Pocket plus rear wall must equal web thickness")
    if not math.isclose(geo["drive_axis_z_mm"], geo["wheel_diameter_mm"]/2):
        raise ValueError("Ground-contact model requires axis height equal to nominal radius")


def support_reactions(weight, cg_xy, contacts):
    """Closed-form three-point vertical equilibrium for one drive axle."""
    left, right, caster = contacts
    axle_x = left[0]
    if not math.isclose(right[0], axle_x):
        raise ValueError("Drive contacts must share x")
    denominator = axle_x-caster[0]
    if abs(denominator) < 1e-12:
        raise ValueError("Degenerate support triangle")
    rc = weight*(axle_x-cg_xy[0])/denominator
    drive_sum = weight-rc
    rl = (weight*cg_xy[1]-rc*caster[1]-right[1]*drive_sum)/(left[1]-right[1])
    return [rl, drive_sum-rl, rc]


def triangle_margin(point, contacts):
    # L,C,R is counterclockwise for this chassis.
    polygon = [contacts[0], contacts[2], contacts[1]]
    margins = []
    for i, a in enumerate(polygon):
        b = polygon[(i+1) % 3]
        dx, dy = b[0]-a[0], b[1]-a[1]
        margins.append((dx*(point[1]-a[1])-dy*(point[0]-a[0]))/math.hypot(dx, dy))
    return min(margins)


def contact_points(c, angle):
    geo = c["geometry"]
    x, half_track = geo["drive_axis_x_mm"], geo["drive_track_mm"]/2
    cx, cy = geo["caster_pivot_xy_mm"]
    trail = geo["caster_trail_mm"]
    return [(x, half_track), (x, -half_track),
            (cx-trail*math.cos(angle), cy-trail*math.sin(angle))]


def static_case(c, name, components, historical=False):
    mass = sum(p["mass_kg"] for p in components)
    cg = [sum(p["mass_kg"]*p["cg_xyz_mm"][i] for p in components)/mass for i in range(3)]
    weight = mass*c["gravity_m_s2"]
    samples = c["geometry"]["caster_orientation_samples"]
    ranges = {key: {"min_signed_N": math.inf, "max_signed_N": -math.inf}
              for key in ("left", "right", "caster")}
    residual = {"force_N": 0.0, "moment_Nmm": 0.0}
    margin = math.inf
    for i in range(samples):
        angle = i*math.tau/samples
        contacts = contact_points(c, angle)
        reactions = support_reactions(weight, cg[:2], contacts)
        for key, reaction in zip(ranges, reactions):
            entry = ranges[key]
            entry["min_signed_N"] = min(entry["min_signed_N"], reaction)
            if reaction > entry["max_signed_N"]:
                entry.update(max_signed_N=reaction, max_at_caster_angle_deg=math.degrees(angle))
        forces = [([x, y, 0], [0, 0, r]) for (x, y), r in zip(contacts, reactions)]
        error = wrench_residual(forces, [0, 0, weight], cross(cg, [0, 0, weight]))
        residual = {key: max(residual[key], error[key]) for key in residual}
        margin = min(margin, triangle_margin(cg, contacts))
    maximum = max(ranges[side]["max_signed_N"] for side in ("left", "right"))
    published = c["motor_current_catalog"]["allowable_radial_load_N"]
    return {
        "name": name, "historical_only": historical,
        "components": components, "gross_mass_kg": mass, "assumed_cg_xyz_mm": cg,
        "caster_samples": samples, "reaction_ranges_N": ranges,
        "all_sampled_reactions_nonnegative": min(v["min_signed_N"] for v in ranges.values()) >= -1e-9,
        "minimum_sampled_support_margin_mm": margin,
        "maximum_drive_vertical_reaction_N": maximum,
        "maximum_drive_vertical_equivalent_kg": maximum/c["gravity_m_s2"],
        "current_published_radial_value_N": published,
        "vertical_reaction_alone_exceeds_published_radial_value": maximum > published,
        "catalog_comparison_status": "conditional_numeric_comparison_only; lot_and_load_datum_unknown; no_division_by_SF",
        "equilibrium_max_abs_residual": residual,
        "operation_approved": False,
    }


def motor_bolt_group(force, moment, mount):
    """No pocket/friction load sharing; normal springs may be compressive."""
    radius = mount["motor_PCD_mm"]/2
    pts = [(radius*math.cos(math.radians(a)), radius*math.sin(math.radians(a)))
           for a in mount["motor_hole_angles_deg"]]
    # The model below requires the symmetric 120-degree group in requirements.
    if abs(sum(x for x, _ in pts))+abs(sum(z for _, z in pts)) > 1e-8:
        raise ValueError("Motor bolt group must be centered")
    if abs(sum(x*z for x, z in pts)) > 1e-8:
        raise ValueError("Motor bolt group principal axes not aligned")
    ix, iz = sum(x*x for x, _ in pts), sum(z*z for _, z in pts)
    polar = ix+iz
    fx, fy, p = force
    mx, my, mz = moment
    bolt_forces = []
    output = []
    for x, z in pts:
        f = [fx/len(pts)+my*z/polar,
             fy/len(pts)-mx*z/iz+mz*x/ix,
             p/len(pts)-my*x/polar]
        bolt_forces.append(([x, 0, z], f))
        output.append({"position_relative_mm": [x, 0, z], "force_on_mount_N": f,
                       "in_plane_shear_N": math.hypot(f[0], f[2])})
    return {
        "model": "equal_stiffness_signed_normal_springs_no_pocket_or_friction; not_actual_bolt_force",
        "bolts": output,
        "maximum_in_plane_shear_N": max(v["in_plane_shear_N"] for v in output),
        "maximum_tensile_direction_spring_force_N": max(0, *(v["force_on_mount_N"][1] for v in output)),
        "maximum_absolute_normal_spring_force_N": max(abs(v["force_on_mount_N"][1]) for v in output),
        "equilibrium_max_abs_residual": wrench_residual(bolt_forces, force, moment),
    }


def frame_bolt_group(force, moment, mount, arm):
    """One outboard compression resultant plus two bolts, with zero friction."""
    fx, fy, p = force
    mx, my, mz = moment
    half_pitch = mount["frame_bolt_pitch_x_mm"]/2
    sum_x2 = 2*half_pitch**2
    compression = mx/arm
    total_tension_component = compression-p
    reactions = [([0, arm, 0], [0, 0, -compression])]
    output = []
    for x in (-half_pitch, half_pitch):
        # Reactions ON the mount; a positive z is the bolt head pulling upward.
        f = [-fx/2, -fy/2-mz*x/sum_x2, total_tension_component/2+my*x/sum_x2]
        reactions.append(([x, 0, 0], f))
        output.append({"position_relative_mm": [x, 0, 0], "reaction_on_mount_N": f,
                       "in_plane_shear_N": math.hypot(f[0], f[1])})
    return {
        "contact_arm_mm_assumed": arm,
        "model": "assumed_contact_resultant_and_rigid_joint; preload_prying_local_contact_unknown",
        "contact_compression_N": compression,
        "bolts": output,
        "maximum_additional_tension_component_N": max(v["reaction_on_mount_N"][2] for v in output),
        "maximum_in_plane_shear_N": max(v["in_plane_shear_N"] for v in output),
        "contact_and_tension_signs_compatible_with_assumption": compression >= 0 and min(v["reaction_on_mount_N"][2] for v in output) >= 0,
        "equilibrium_max_abs_residual": wrench_residual(reactions, scale(force, -1), scale(moment, -1)),
    }


def module_load_case(c, service_p, service_torque, lateral_ratio, factor):
    geo, mount = c["geometry"], c["mount"]
    radius = geo["wheel_diameter_mm"]/2
    service_force = [service_torque*1000/radius, lateral_ratio*service_p, service_p]
    force = scale(service_force, factor)
    wheel_y = geo["drive_track_mm"]/2
    frame_arm = [0, wheel_y-geo["outer_rail_center_y_mm"], -geo["frame_bottom_top_z_mm"][0]]
    motor_arm = [0, wheel_y-geo["motor_fixed_face_y_mm"], -geo["drive_axis_z_mm"]]
    frame_moment, motor_moment = cross(frame_arm, force), cross(motor_arm, force)
    catalog = c["motor_current_catalog"]
    radial_proxy, axial_proxy = math.hypot(service_force[0], service_force[2]), abs(service_force[1])
    assumed_service_allowable = (c["strength"]["procurement_minimum_yield_requirement_MPa"]
                                / c["strength"]["static_safety_factor_target"])
    return {
        "service_torque_comparison_Nm": service_torque,
        "lateral_ratio_sensitivity_NOT_LIMIT": lateral_ratio,
        "linear_load_multiplier": factor,
        "service_force_xyz_N": service_force,
        "applied_force_xyz_N": force,
        "frame_joint_moment_xyz_Nmm": frame_moment,
        "motor_face_moment_xyz_Nmm": motor_moment,
        "gross_section_bending": [
            {"assumed_width_mm": b, "thickness_mm": mount["flange_thickness_mm"],
             "sigma_from_Mx_only_MPa": abs(frame_moment[0])*6/(b*mount["flange_thickness_mm"]**2),
             "service_Mx_only_stress_over_assumed_allowable":
                 abs(frame_moment[0])*6/(factor*b*mount["flange_thickness_mm"]**2*assumed_service_allowable),
             "scope": "gross_Mx_only_not_full_von_Mises_or_local_joint_qualification"}
            for b in mount["gross_section_width_sensitivity_mm"]],
        "frame_bolt_contact_models": [frame_bolt_group(force, frame_moment, mount, arm)
                                      for arm in mount["frame_contact_arm_sensitivity_mm"]],
        "motor_bolt_no_sharing_model": motor_bolt_group(force, motor_moment, mount),
        "service_catalog_force_comparison": {
            "uses_unfactored_service_vector_only": True,
            "radial_force_proxy_sqrt_Fx2_Fz2_N": radial_proxy,
            "axial_force_proxy_abs_Fy_N": axial_proxy,
            "radial_proxy_exceeds_published_value": radial_proxy > catalog["allowable_radial_load_N"],
            "axial_proxy_exceeds_published_value": axial_proxy > catalog["allowable_axial_load_N"],
            "status": "conditional_comparison_only; load_datum_combined_load_rule_and_lot_unknown; not_a_SF_check",
        },
    }


def drive_case(c, mass, slope, acceleration=None):
    d = c["drive"]
    g = c["gravity_m_s2"]
    a = d["acceleration_m_s2"] if acceleration is None else acceleration
    theta = math.radians(slope)
    force = mass*(a+g*math.sin(theta)+d["rolling_resistance_assumed"]*g*math.cos(theta))
    torque = force*c["geometry"]["wheel_diameter_mm"]/2000/2
    margin_torque = torque*d["sizing_margin_factor"]
    return {"mass_kg": mass, "slope_deg": slope, "acceleration_m_s2": a,
            "total_tractive_force_N": force, "torque_per_wheel_Nm": torque,
            "torque_with_sizing_margin_Nm": margin_torque,
            "catalog_rated_to_margin_requirement_ratio": d["rated_torque_Nm"]/margin_torque if margin_torque else None,
            "margin_requirement_exceeds_catalog_rated_torque": margin_torque > d["rated_torque_Nm"],
            "operation_approved": False}


def fit_and_beam(c, p):
    f, m, b, stiff = c["fit"], c["mount"], c["frame_beam_comparison"], c["stiffness"]
    flat_nom = f["pocket_flat_distance_nominal_mm"]-f["motor_flat_distance_nominal_mm"]
    flat_tol = f["pocket_flat_distance_tolerance_pm_mm"]+f["motor_flat_distance_tolerance_pm_mm"]
    arc_nom = f["pocket_main_arc_radius_nominal_mm"]-f["motor_boss_diameter_nominal_mm"]/2
    arc_min = (f["pocket_main_arc_radius_nominal_mm"]-f["pocket_main_arc_radius_tolerance_pm_mm"]
               -(f["motor_boss_diameter_nominal_mm"]+f["motor_boss_diameter_upper_deviation_mm"])/2)
    arc_max = (f["pocket_main_arc_radius_nominal_mm"]+f["pocket_main_arc_radius_tolerance_pm_mm"]
               -(f["motor_boss_diameter_nominal_mm"]+f["motor_boss_diameter_lower_deviation_mm"])/2)
    load_a = c["geometry"]["drive_axis_x_mm"]-b["left_end_x_mm"]
    load_b = b["span_mm"]-load_a
    if min(load_a, load_b) <= 0:
        raise ValueError("Comparison load must lie inside the hypothetical beam")
    delta = p*load_a**2*load_b**2/(3*stiff["elastic_modulus_assumed_MPa"]*b["second_moment_mm4"]*b["span_mm"])
    sigma = p*load_a*load_b*b["extreme_fiber_distance_mm"]/(b["span_mm"]*b["second_moment_mm4"])
    side_offset = m["motor_PCD_mm"]/2*math.sqrt(3)/2
    return {
        "one_sided_flat_gap_mm": {"min": flat_nom-flat_tol, "nominal": flat_nom, "max": flat_nom+flat_tol},
        "one_sided_main_arc_radial_gap_mm": {"min": arc_min, "nominal": arc_nom, "max": arc_max},
        "D1_D2_full_corner_profile_fit_verified": False,
        "lower_motor_hole_to_rear_slot_ligament_mm": side_offset-m["motor_clearance_hole_diameter_mm"]/2-m["cable_rear_throat_width_mm"]/2,
        "lower_motor_head_edge_to_rear_slot_mm": side_offset-m["motor_screw_head_diameter_mm"]/2-m["cable_rear_throat_width_mm"]/2,
        "motor_screw_nominal_engagement_mm": m["motor_screw_nominal_length_mm"]-m["rear_wall_mm"],
        "motor_screw_nominal_bottoming_margin_mm": m["motor_thread_depth_max_mm"]-(m["motor_screw_nominal_length_mm"]-m["rear_wall_mm"]),
        "head_seating_annulus_mm2": {
            "motor_M2p5": math.pi/4*(m["motor_screw_head_diameter_mm"]**2-m["motor_clearance_hole_diameter_mm"]**2),
            "frame_M6": math.pi/4*(m["frame_screw_head_diameter_mm"]**2-m["frame_clearance_hole_diameter_mm"]**2)},
        "axis_stiffness_needed_if_candidate_accepted_N_per_mm": p/stiff["axis_displacement_candidate_mm"],
        "stiffness_candidate_accepted": stiff["candidate_accepted"],
        "hypothetical_single_rail_beam": {
            "service_load_N": p, "load_distances_from_ends_mm": [load_a, load_b],
            "sigma_MPa": sigma, "deflection_at_load_mm": delta,
            "status": "reference_beam_only_not_actual_mount_displacement_or_pass_fail"},
        "pocket_two_point_comparison": [
            {"span_mm": span,
             "inner_reaction_N": p*(1-(c["geometry"]["drive_track_mm"]/2-c["geometry"]["motor_fixed_face_y_mm"])/span),
             "outer_reaction_N": p*(c["geometry"]["drive_track_mm"]/2-c["geometry"]["motor_fixed_face_y_mm"])/span,
             "status": "no_end_face_or_bolt_sharing_not_actual_contact_force"}
            for span in m["pocket_two_point_span_sensitivity_mm"]],
    }


def module_cases(c, service_p):
    return [module_load_case(c, service_p, torque, lateral, factor)
            for factor in (1, c["strength"]["static_safety_factor_target"])
            for torque in c["strength"]["service_torque_comparison_Nm"]
            for lateral in c["strength"]["lateral_force_over_vertical_sensitivity"]]


def width_geometry(c, mount, relief_half_width, root_radius):
    """Nominal distances from input dimensions, without a STEP/tolerance check."""
    axis_x = c["geometry"]["drive_axis_x_mm"]
    flange_half, web_half = mount["flange_width_mm"]/2, mount["web_width_mm"]/2
    pitch_half = mount["frame_bolt_pitch_x_mm"]/2
    head_r, hole_r = mount["frame_screw_head_diameter_mm"]/2, mount["frame_clearance_hole_diameter_mm"]/2
    motor_r = mount["motor_PCD_mm"]/2
    motor_xmax = max(abs(motor_r*math.cos(math.radians(a))) for a in mount["motor_hole_angles_deg"])
    motor_head_top = (c["geometry"]["drive_axis_z_mm"]
                      + max(motor_r*math.sin(math.radians(a)) for a in mount["motor_hole_angles_deg"])
                      + mount["motor_screw_head_diameter_mm"]/2)
    flange_top = c["geometry"]["frame_bottom_top_z_mm"][0]
    flange_bottom = flange_top-mount["flange_thickness_mm"]
    tip = flange_bottom+mount["frame_screw_nominal_length_mm"]
    nut_low, nut_high = mount["frame_slotnut_z_limits_mm"]
    return {
        "flange_x_limits_mm": [axis_x-flange_half, axis_x+flange_half],
        "web_x_limits_mm": [axis_x-web_half, axis_x+web_half],
        "frame_bolt_x_mm": [axis_x-pitch_half, axis_x+pitch_half],
        "frame_hole_center_to_flange_outer_edge_mm": flange_half-pitch_half,
        "frame_hole_center_to_unfilleted_web_edge_mm": pitch_half-web_half,
        "frame_hole_edge_to_flange_outer_edge_mm": flange_half-pitch_half-hole_r,
        "frame_hole_edge_to_unfilleted_web_edge_mm": pitch_half-web_half-hole_r,
        "frame_head_edge_to_flange_outer_edge_mm": flange_half-pitch_half-head_r,
        "frame_head_edge_to_unfilleted_web_edge_mm": pitch_half-web_half-head_r,
        "motor_hole_edge_to_web_outer_edge_mm": web_half-motor_xmax-mount["motor_clearance_hole_diameter_mm"]/2,
        "motor_head_edge_to_web_outer_edge_mm": web_half-motor_xmax-mount["motor_screw_head_diameter_mm"]/2,
        "main_arc_only_to_web_outer_edge_mm": web_half-c["fit"]["pocket_main_arc_radius_nominal_mm"],
        "R2_relief_cut_half_width_mm": relief_half_width,
        "R2_relief_to_web_outer_edge_nominal_mm": web_half-relief_half_width,
        "flange_bottom_top_z_mm": [flange_bottom, flange_top],
        "frame_screw_tip_z_mm": tip,
        "frame_screw_overlap_with_nominal_nut_mm": max(0, min(tip, nut_high)-max(flange_bottom, nut_low)),
        "frame_screw_tip_beyond_nominal_nut_top_mm": tip-nut_high,
        "frame_screw_tip_to_slot_cavity_top_mm": mount["frame_slot_cavity_top_z_mm"]-tip,
        "frame_head_bottom_z_mm": flange_bottom-mount["frame_screw_head_height_mm"],
        "upper_motor_head_top_z_mm": motor_head_top,
        "upper_motor_head_to_flange_underside_z_gap_mm": flange_bottom-motor_head_top,
        "upper_motor_head_to_long_root_fillet_bbox_z_gap_mm": flange_bottom-root_radius-motor_head_top,
        "frame_head_seating_annulus_mm2": math.pi*(head_r**2-hole_r**2),
        "scope": "nominal_2D_dimension_chain_only; fillet_shape_tool_access_chamfers_effective_threads_and_tolerances_unverified",
    }
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

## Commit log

2026-09-20 Initial commit: FreeCAD sample and setup documentation
    [CenterHolePlate.FCStd, CenterHolePlate.step]
2026-09-20 Add costed AMR first CAD design and FreeCAD screenshots
    [AMR01_FirstDesign_A.FCStd, AMR01_FirstDesign_A.step, BOM.csv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]
2026-09-20 Design second AMR chassis and compare top-mounted drive
    [AMR01_Option_C_TopMotor.FCStd, AMR01_Option_C_TopMotor.step, AMR01_SecondDesign_B.FCStd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]
2026-09-20 Rebuild first AMR chassis without spacers and lower battery tray
    [AMR01_Revision_A2.FCStd, AMR01_Revision_A2.step, BOM.csv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]
2026-09-20 Review battery service and wiring layout against real robot drive examples
    [AMR01_ElectricalLayout_A2.FCStd, BOM.csv]
2026-09-20 Add DDSM115 A3 CAD study, verified layouts and tire replacement cost review
    [AMR01_DDSM115_A3.FCStd, AMR01_DDSM115_A3.step, AMR01_ElectricalLayout_A3.FCStd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]
2026-09-21 Revise A4 chassis for M0601C motors and compact CNC mounts
    [AMR01_ElectricalLayout_A4.FCStd, AMR01_M0601C_A4.FCStd, AMR01_M0601C_A4.step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]
2026-09-21 Record actual CNC quote and add reusable quoting skill
    [BOM.csv]
2026-09-21 Compare wheel mount machining quotes and 15kg load cases; add PLA fit mocks
    [AMR01_M0601C_A5.FCStd, AMR01_M0601C_A5.step, BOM_cost_comparison.csv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]
2026-09-21 Revise A6 payload limits, cargo deck and motor mounting interfaces
    [AMR01_M0601C_A6.FCStd, AMR01_M0601C_A6.step, BOM.csv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]
2026-09-21 Set flat-floor prototype scope without an added mechanical brake
    [AMR01_M0601C_A6.FCStd]
2026-09-21 Add procurement BOM with CAD quantities and tax-corrected costs
    [BOM.csv, BOM.xlsx, BOM_CAD_MAP.csv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]
2026-09-21 Add printable gridded deck concept with support and cost comparison
    [AMR01_PrintedDeck_P0.FCStd, AMR01_PrintedDeck_P0.step, PrintedDeckPanel1.stl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]
2026-09-21 Quote aluminum grid decks and select home-center caster pickup
    [AMR_GridDeck_C45_Q1.FCStd, AMR_GridDeck_C45_Q1.step, AMR_GridDeck_T4_Q1.FCStd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]
2026-09-21 Select locally available TYG-50 caster and verify load margin
    [AMR01_M0601C_A6.FCStd, AMR01_M0601C_A6.step, BOM.csv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]
2026-09-21 Compare lower-cost perforated deck stock and printed panels
2026-09-21 Adopt CNC grid deck with PLA fixtures and verify assembly clearances
    [AMR01_M0601C_A6.FCStd, AMR01_M0601C_A6.step, AMR_GridDeck_C45_D2.FCStd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]
2026-09-21 Document PLA deck fastening with a sectioned CAD view
    [P0_Fastener_Detail.FCStd]
2026-09-21 Reject deck supports that require cutting and drilling solid bars
2026-09-21 Replace printed deck support bars with precut 3030 and stock brackets
    [AMR01_PrintedDeck_P1.FCStd, AMR01_PrintedDeck_P1.step, BOM.csv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]
2026-09-21 Normalize P1 export whitespace and CSV line endings
    [AMR01_PrintedDeck_P1.step, BOM.csv]
2026-09-21 Show installed expansion grid deck and add top CAD view
2026-09-21 Record unresolved support and fastening at printed deck seams
2026-09-21 Restore aluminum deck directly on lower frame and resolve clearances
    [AMR01_AluminumDirect_D3.FCStd, AMR01_AluminumDirect_D3.step, AMR_GridDeck_C45_D3.FCStd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]
2026-09-22 Add D4 side battery drawer with pack restraints and service clearance checks
    [AMR01_BatteryDrawer_D4.FCStd, AMR01_BatteryDrawer_D4.step, BOM.csv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]
2026-09-22 Select Makita 18V power and add rear battery service bay
    [AMR01_MakitaPower_D5-with-power-envelopes.step, AMR01_MakitaPower_D5.FCStd, AMR01_MakitaPower_D5.step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]
2026-09-22 Redesign D6 with first-floor electronics and independent upper cargo deck
    [AMR01_TwoStorey_D6-with-equipment-envelopes.step, AMR01_TwoStorey_D6.FCStd, AMR01_TwoStorey_D6.step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]
2026-09-22 Review D6 single-sided frame joints and reinforcement candidates
2026-09-22 Reinforce D6 post bases and clarify payload and cost budgets
    [AMR01_TwoStorey_D6-with-equipment-envelopes.step, AMR01_TwoStorey_D6.FCStd, AMR01_TwoStorey_D6.step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]
2026-09-22 Add D6.1 URDF assets and Isaac Sim 5 import workflow
    [amr_d61.urdf, amr_d61_payload_10kg.urdf, base_link_aluminum.stl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]
2026-09-22 Reinforce D6.2 floor panels with four distributed fixings
    Anchor the printed seam beam at both ends, add tapered underside ribs, and retain battery and computer access. Treat 10 kg as a soft vehicle target and recalculate the 10 kg cargo cases through a 10.5 kg vehicle envelope. Regenerate CAD, print files, BOM, screenshots, URDF and the verified MuJoCo motion GIF.
    [AMR01_TwoStorey_D6-with-equipment-envelopes.step, AMR01_TwoStorey_D6.FCStd, AMR01_TwoStorey_D6.step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]
2026-09-22 Extend D6.3 floor corners and remove auxiliary flat gussets
    Keep eight independent HBLFSN6 frame joints and four fixings per floor panel. Remove four notched flat plates and their eight fastener sets after detecting half-supported washer seats. Update CAD, print files, BOM, reviews, screenshots and simulation assets; retain explicit limits on physical joint stiffness qualification.
    [AMR01_TwoStorey_D6-with-equipment-envelopes.step, AMR01_TwoStorey_D6.FCStd, AMR01_TwoStorey_D6.step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]
2026-09-22 Analyze D6.3 PLA floor deflection, strap loads and fixing limits
    [FloorPLA_0_0.step, FloorPLA_0_1.step, FloorPLA_1_0.step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]
2026-09-22 Replace PLA floor countersinks with plain M4 holes and large washers
    [AMR01_TwoStorey_D6-with-equipment-envelopes.step, AMR01_TwoStorey_D6.FCStd, AMR01_TwoStorey_D6.step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]
2026-09-23 Cover computer floor fasteners with a removable PLA barrier
    Add a continuous 2 mm cover over the four M4 heads and washers, retain aligned case supports, and distinguish the unselected PCB mount from the contact barrier. Update saved CAD, screenshots, printab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
    [AMR01_TwoStorey_D6-with-equipment-envelopes.step, AMR01_TwoStorey_D6.FCStd, AMR01_TwoStorey_D6.step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]
2026-09-23 Publish complete BOM in readable Markdown alongside CSV
2026-09-23 Add D6.7 torque-hinged deck and rear controls with costed BOM
    [AMR01_HingedDeck_D67-structure.step, AMR01_HingedDeck_D67.FCStd, AMR01_HingedDeck_D67.step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]
2026-09-23 Redesign D6.8 with frame-mounted metal hinges and floor-supported controls
    [AMR01_DirectHinge_D68-structure.step, AMR01_DirectHinge_D68.FCStd, AMR01_DirectHinge_D68.step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]
2026-09-23 Document direct-mount torque hinge search and rejected fit trial
    [AMR_Hinge_DirectFit_Study.FCStd]
2026-09-23 Replace torque hinges with six-bolt fixed deck
    [AMR01_FixedDeck_D69-structure.step, AMR01_FixedDeck_D69.FCStd, AMR01_FixedDeck_D69.step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]
2026-09-23 Withdraw unbuildable custom electronics and record no-solder requirements
    [BOM-summary.csv, BOM.csv, withdrawn-parts.csv]
2026-09-23 Limit initial electrical scope to manual drive and power emergency stop
    [BOM-summary.csv, BOM.csv, deferred-parts.csv]
2026-09-23 Restore onboard Linux computer and clarify powered braking versus power cutoff
    [BOM.csv, deferred-parts.csv]
2026-09-23 Revise AMR electrical layout for Pico RS485 HAT and direct motor cutoff
    [AMR01_PicoControl_E3.FCStd, AMR01_PicoControl_E3.step, BOM-summary.csv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]
2026-09-23 Revise deck and switch mounts after independent reviews; add optional monitor CAD
    [AMR01_OptionalMonitor_O1.FCStd, AMR01_OptionalMonitor_O1.step, AMR01_Reviewed_E4.FCStd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]
2026-09-23 Apply published switch dimensions and distinguish missing specifications from physical tests
    [AMR01_OptionalMonitor_O1.FCStd, AMR01_OptionalMonitor_O1.step, AMR01_Reviewed_E4.FCStd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]
